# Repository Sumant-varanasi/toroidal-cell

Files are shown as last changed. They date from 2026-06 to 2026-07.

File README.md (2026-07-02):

# Toroidal Multipass Cell (TMPC) Platform

A Python toolkit for **designing, simulating, tolerancing, and visualising
Toroidal Multipass Cells** (TMPC) for laser absorption spectroscopy at 1.654 µm
(CH₄). The project pairs a custom 3-D ray tracer with an astigmatic
Gaussian-beam model, a full Monte-Carlo tolerance engine, multi-objective design
exploration, and interactive 3-D / photorealistic visualisation.

Multipass cells fold a long optical path into a compact volume by bouncing a
laser many times between mirrors — the more path, the more sensitive the gas
sensor. This repository explores toroidal-mirror geometries that support both
Herriott-style *ring* patterns and Tuzson/Graf-style *spiral* (up-down)
patterns, and provides the tooling to pick, tolerance, and validate a real
design.

The current, definitive model lives in
**[`_CURRENT/tmpc_platform_v5/`](_CURRENT/tmpc_platform_v5/)** — a self-contained
superset of the earlier iterations.

## Headline result — verified drone cell designs (July 2026)

**[`_CURRENT/drone_20m/`](_CURRENT/drone_20m/README.md)** holds a menu of
**fully verified drone-mountable designs using only catalog Thorlabs 1″ gold
mirrors** (N = 8–16, exact 3-D ray trace, Optiland-cross-validated, every
physical check enforced):

| envelope | OPL | throughput @ R=0.985 | build |
|---|---|---|---|
| Ø180 mm | **24.8 m** | 7.1 % | 16 × CM254-200-M01 |
| Ø180 mm | **20.4 m** | **11.5 %** | 16 × CM254-150-M01 (preset `drone_20m`) |
| Ø159 mm | **20.6 m** | 7.9 % | 13 × CM254-050-M01 (preset `drone_16cm`) |
| Ø143 mm | 13.6 m | 13.8 % | 12 × CM254-250-M01 |

(Published toroidal cells of this size class demonstrate ~10 m.) Each design
ships with an as-built spec — machined mirror placements, mode-matching lens
setting, launch tilts, detector pickoff, per-mirror spot maps — plus
Monte-Carlo tolerances and an ROC-compensation assembly rule.

<p align="center">
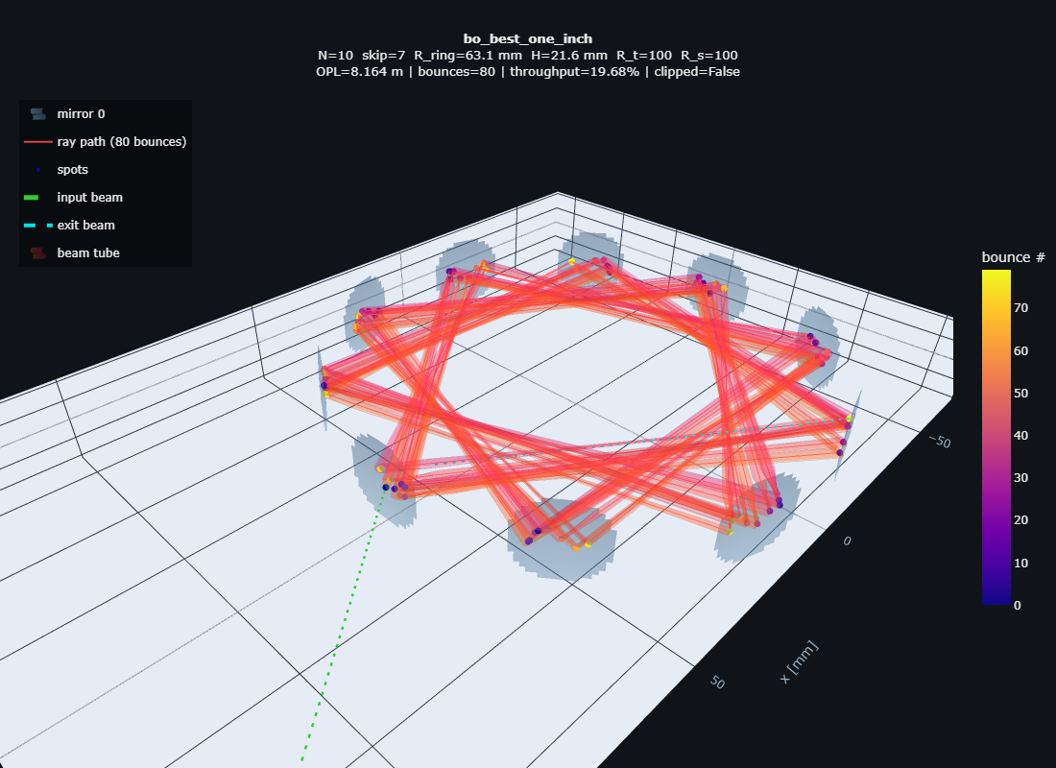
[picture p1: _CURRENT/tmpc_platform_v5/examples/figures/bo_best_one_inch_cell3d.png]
3D ray path + beam tube
  
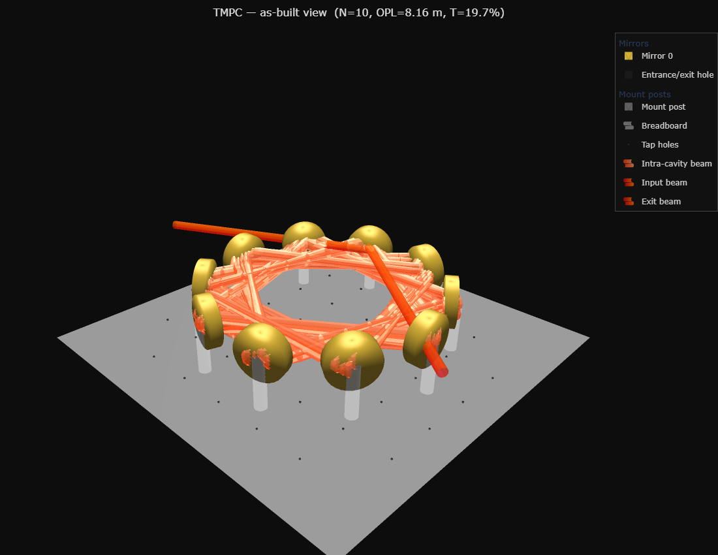
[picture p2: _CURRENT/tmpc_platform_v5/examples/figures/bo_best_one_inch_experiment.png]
As-built experiment render
  
</p>

*Left: the true ray-traced path with the beam rendered as a tube. Right: the
same cell as an "as-built" assembly — gold 1" mirrors, mounts, breadboard, and
the laser bouncing through it.*

---

## Repository layout

The definitive model is consolidated under **`_CURRENT/`** for easy access; the
older iterations remain at the repo root for reference.

| Path | Description |
| --- | --- |
| **`_CURRENT/`** | **Everything current** — the definitive model, gathered together |
| **`_CURRENT/tmpc_platform_v5/`** | **Latest platform.** Full physics, tolerancing, optimisation and visualisation. |
| `_CURRENT/tmpc_platform_v5/examples/` | Rendered figure gallery (3-D views, as-built renders, spot constellations, tolerance plots). |
| `tmpc_platform_v4/`, `tmpc_platform_v2/`, `tmpc_platform/` | Earlier iterations, kept for reference. |
| `run.py` | Standalone Optiland cross-validation of the ray tracer. |
| `test.py` | Quick checks / scratch script. |
| `.venv/`, `requirements.txt` | Shared Python runtime and pinned dependencies. |
| `file_toroidal_cell/`, `toroidal-cell/`, `files (1)/`, `files (2)/` | Historical archives and generated artefacts (CSVs, figures). |

See the **[figure gallery](_CURRENT/tmpc_platform_v5/examples/README.md)** for the
full set of rendered outputs.

<p align="center">
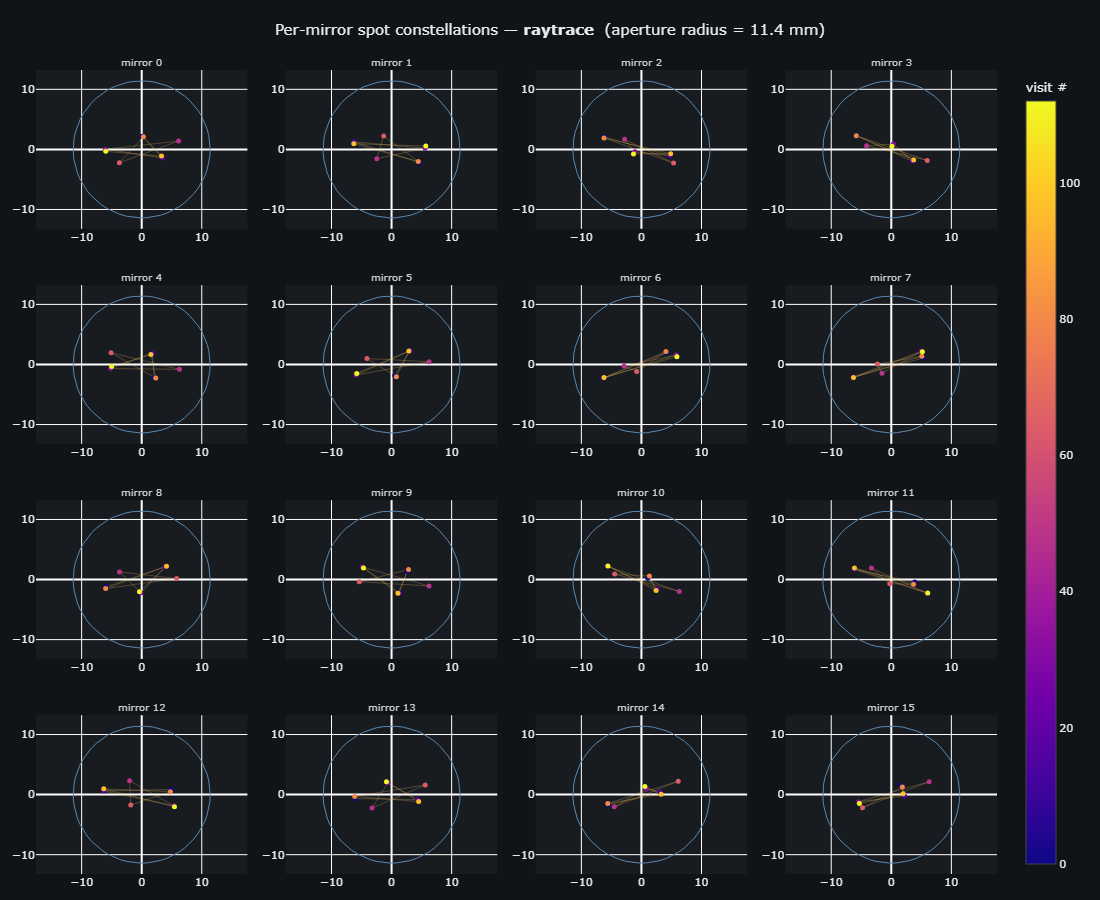
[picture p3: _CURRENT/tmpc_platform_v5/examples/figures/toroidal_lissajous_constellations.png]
Per-mirror spot constellations
  
</p>

*Per-mirror spot pattern for a toroidal (R_t ≠ R_s) design — the astigmatic
Lissajous footprints on each mirror face.*

---

## What v5 does

**Physics** (`physics.py`, `beam.py`) — exact 3-D ray tracing on toroidal mirror
surfaces (analytic normal, Newton-iterated intersection) with per-bounce
angle-of-incidence and hard-aperture clipping. Two topologies are supported: a
*ring* (Herriott-style rotating polygon) and a *spiral* (up-down) cell. Beam
propagation uses a realistic astigmatic M²-corrected Gaussian model in which the
tangential and sagittal radii evolve independently. A loss budget, isotropic and
per-plane stability, re-entrance score, volume utilisation, and spot-pattern
diagnostics are all computed.

**Tolerances** (`tolerance.py`) — per-mirror and global truncated-normal
perturbations, a Monte-Carlo yield study with continuous walk-off metrics,
one-at-a-time sensitivity analysis, and an RSS tolerance-budget allocator.
Presets range from loose to flight-grade, with thermal and vibration factories.

**Visualisation** (`viz3d.py`, `render.py`, `plots.py`) — interactive Plotly 3-D
cell views with the real ray path and beam tube, per-mirror spot constellations,
a photoreal "as-built" render, and publication-ready matplotlib figures.

**Design exploration & validation** — Sobol/LHS sampling with Thorlabs catalogue
snapping, parallel dataset generation, random + Bayesian optimisation, a
RandomForest surrogate, a dependency-free Pareto front, and validation via
analytic cross-checks, ABCD-vs-raytrace residuals, and optional Optiland
cross-validation.

---

## Installation

```bash
git clone https://github.com/Sumant-varanasi/toroidal-cell.git
cd toroidal-cell
python -m venv .venv
# Windows: .venv\Scripts\activate  |  Linux/macOS: source .venv/bin/activate
pip install -r requirements.txt
```

Core dependencies are NumPy, SciPy, pandas and matplotlib. Optional features use
`plotly`, `optiland`, `scikit-optimize` and `scikit-learn`; these are
soft-imported and skipped with a clear message if absent.

> The model is invoked as a package (`python -m tmpc_platform_v5 …`), so run the
> commands **from inside `_CURRENT/`** where the package lives. The examples
> below use the shared virtualenv one level up at `../.venv`.

---

## Quick start (CLI)

```bash
cd _CURRENT
PY=../.venv/Scripts/python.exe   # Linux/macOS: ../.venv/bin/python

# list named design points and simulate one
$PY -m tmpc_platform_v5 presets
$PY -m tmpc_platform_v5 simulate --preset longest_opl

# one design from raw parameters, full physics report
$PY -m tmpc_platform_v5 simulate --N 12 --R_ring 60 --R_t 120 --R_s 180 --chord_skip 5

# Monte-Carlo tolerance study (sensitivity + RSS budget + plots)
$PY -m tmpc_platform_v5 tolerance --preset bo_best_one_inch --tol-preset research --n-trials 300

# interactive 3-D + spot constellations, and an "as-built" render
$PY -m tmpc_platform_v5 visualize --preset toroidal_lissajous --out-dir results/viz
$PY -m tmpc_platform_v5 render --preset bo_best_one_inch --out results/render/exp.html

# physics validation (analytic + ABCD + Optiland if installed), and a Pareto front
$PY -m tmpc_platform_v5 validate --N 8 --chord_skip 1
$PY -m tmpc_platform_v5 pareto --n 512
```

## Quick start (Python API)

```python
from tmpc_platform_v5 import TMPCConfig, simulate_tmpc, ToleranceSpec, full_report

cfg = TMPCConfig(N=12, R_ring=60, H=40, R_t=120, R_s=180,
                 chord_skip=5, w0=0.5, M2=1.1, input_offset_z=-2.0)
cfg.n_passes = 8 * cfg.N
res = simulate_tmpc(cfg)
print(res.bounces, res.opl, res.throughput, res.stability_tan, res.stability_sag)

# full tolerance report (Monte-Carlo + sensitivity + budget)
rep = full_report(cfg, ToleranceSpec.research_grade(), n_trials=300, metric="exit_drift_mrad")
print(rep["summary"], rep["sensitivity"], rep["budget"])
```

## Conventions

All lengths are in millimetres, wavelength in mm (`1.654e-3` = 1654 nm), and
angles in radians unless a name ends in `_deg`/`_mrad`.

## Validating the ray tracer

`run.py` rebuilds the same cell geometry in the open-source
[Optiland](https://github.com/HarrisonKramer/optiland) package and compares
per-bounce spot positions, chord length, and angle of incidence against the
custom NumPy tracer.

---

> IP note: per the IITD-Abu Dhabi / Aston joint brief, all IP belongs to Aston.
> Internal use only.

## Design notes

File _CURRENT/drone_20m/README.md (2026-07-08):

# Drone TMPC design suite — verified 1″-mirror cells, Ø140–180 mm, 13.6–24.8 m OPL

Design brief (2026-07-02): a drone-mountable toroidal multipass cell for CH₄
TDLAS at 1654 nm — target ~20 m OPL, assembly diameter safely under 190 mm
(smaller better), **N = 8–16** Thorlabs 1″ protected-gold concave mirrors
(CM254-xxx-M01), entrance-hole radius 1.3 mm, 1.3 mm collimated input beam,
reflectivity assumed 0.984–0.985 (throughput reported parametrically in R).

Every design below is verified by the exact 3-D ray tracer
(`tmpc_platform_v5`) against the full physical-check matrix: exit through the
entrance hole, no early hole leakage, 1/e² beam edge inside every clear
aperture, no spot overlap anywhere (fringe safety), per-plane astigmatic
stability, mirror packing, and the envelope cap. Optiland cross-validation
reproduces the traced path to 0.000 µm RMS.

<p align="center">
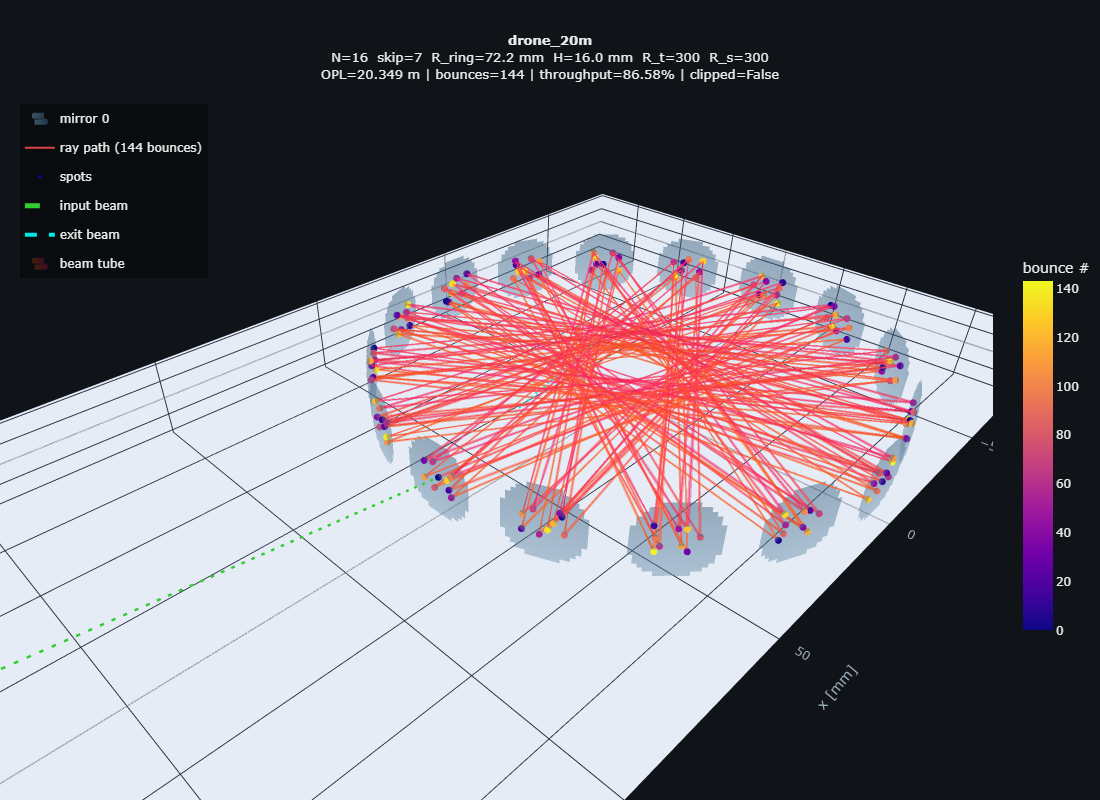
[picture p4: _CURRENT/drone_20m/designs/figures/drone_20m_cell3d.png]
drone_20m: 144-bounce light path in the 16-mirror ring
  
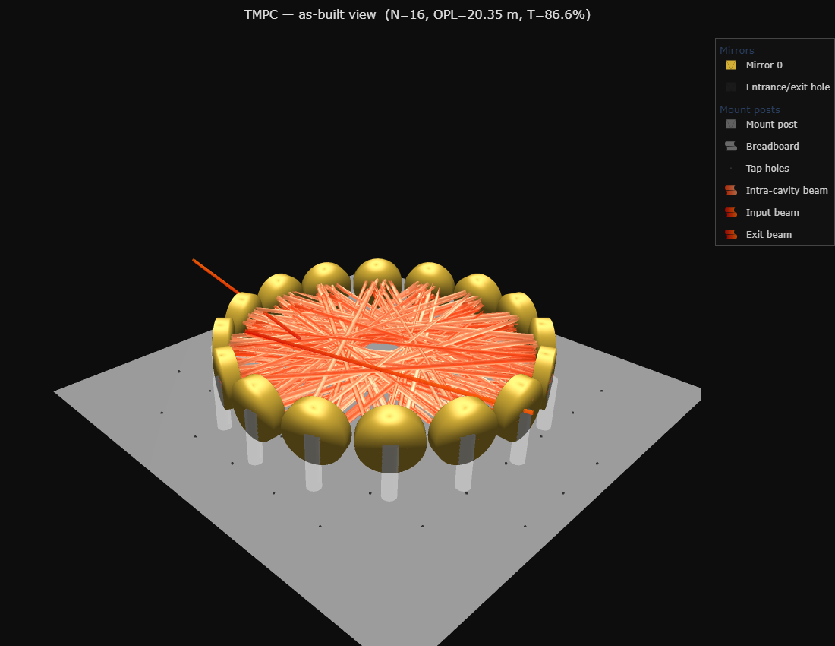
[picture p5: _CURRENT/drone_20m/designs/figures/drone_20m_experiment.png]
drone_20m as-built render
  
</p>

*Left: the traced light path of `drone_20m` — 144 chords between 16 catalog
mirrors, input (green) and exit beams through the hole in mirror 0.
Right: the same cell rendered as built. Interactive versions:
[cell3d.html](designs/figures/drone_20m_cell3d.html),
[experiment.html](designs/figures/drone_20m_experiment.html).*

<p align="center">
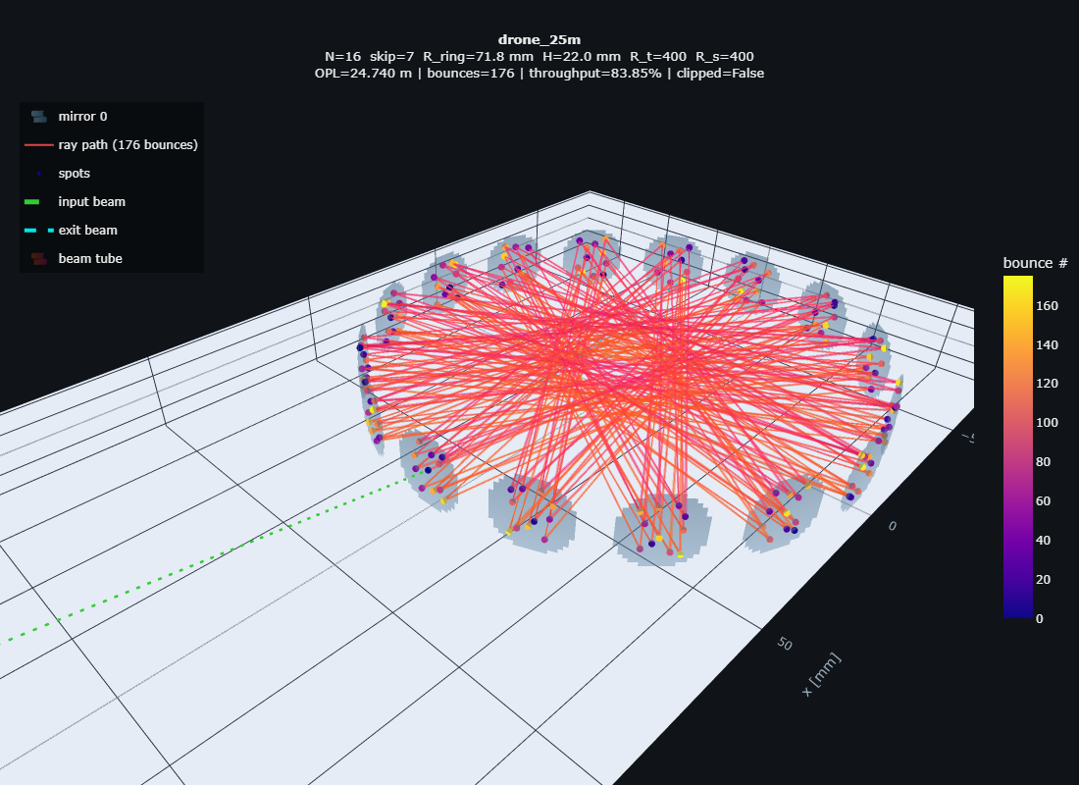
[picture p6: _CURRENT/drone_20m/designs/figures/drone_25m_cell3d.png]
drone_25m: 176-bounce light path (24.8 m)
  
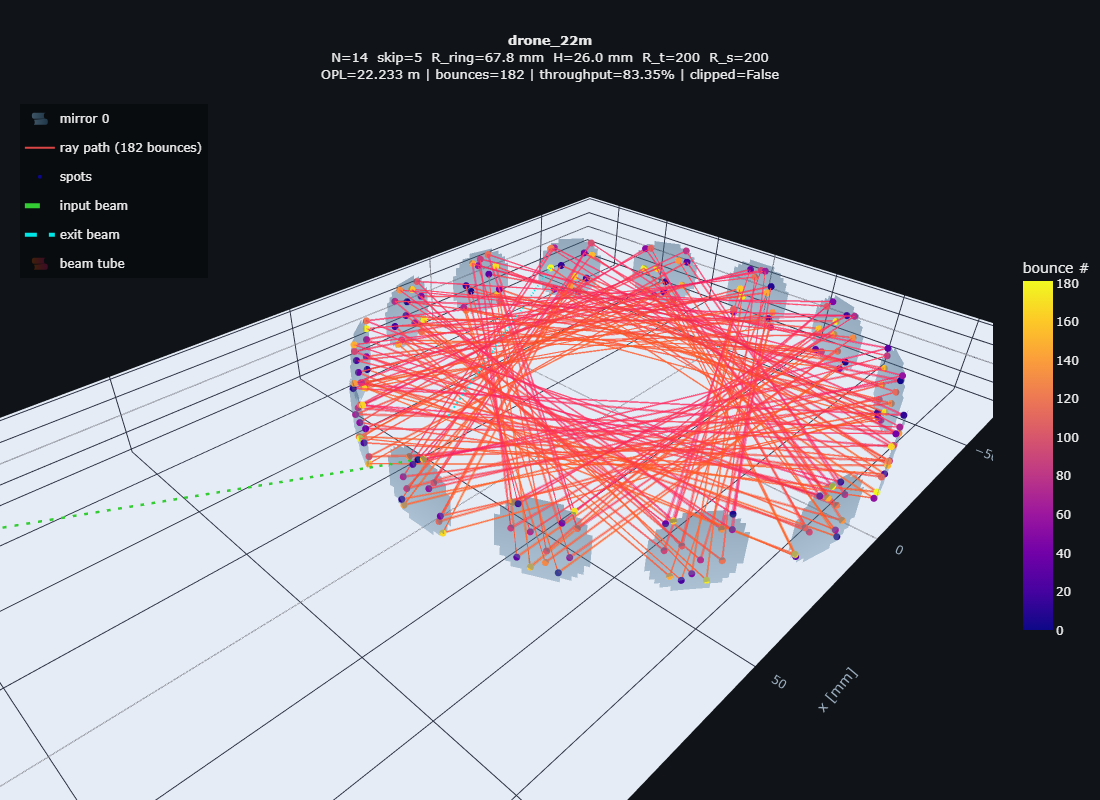
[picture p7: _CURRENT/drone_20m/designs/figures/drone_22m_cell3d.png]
drone_22m: 182-bounce light path (22.3 m)
  
</p>

*The longer-path corners: `drone_25m` (left — 176 chords, 24.77 m, 11 spots
per mirror in the same 180 mm envelope) and the new `drone_22m` (right —
182 chords, 22.25 m in 172 mm). At R = 0.999 these extra passes cost only
~3 % of signal.*

<p align="center">
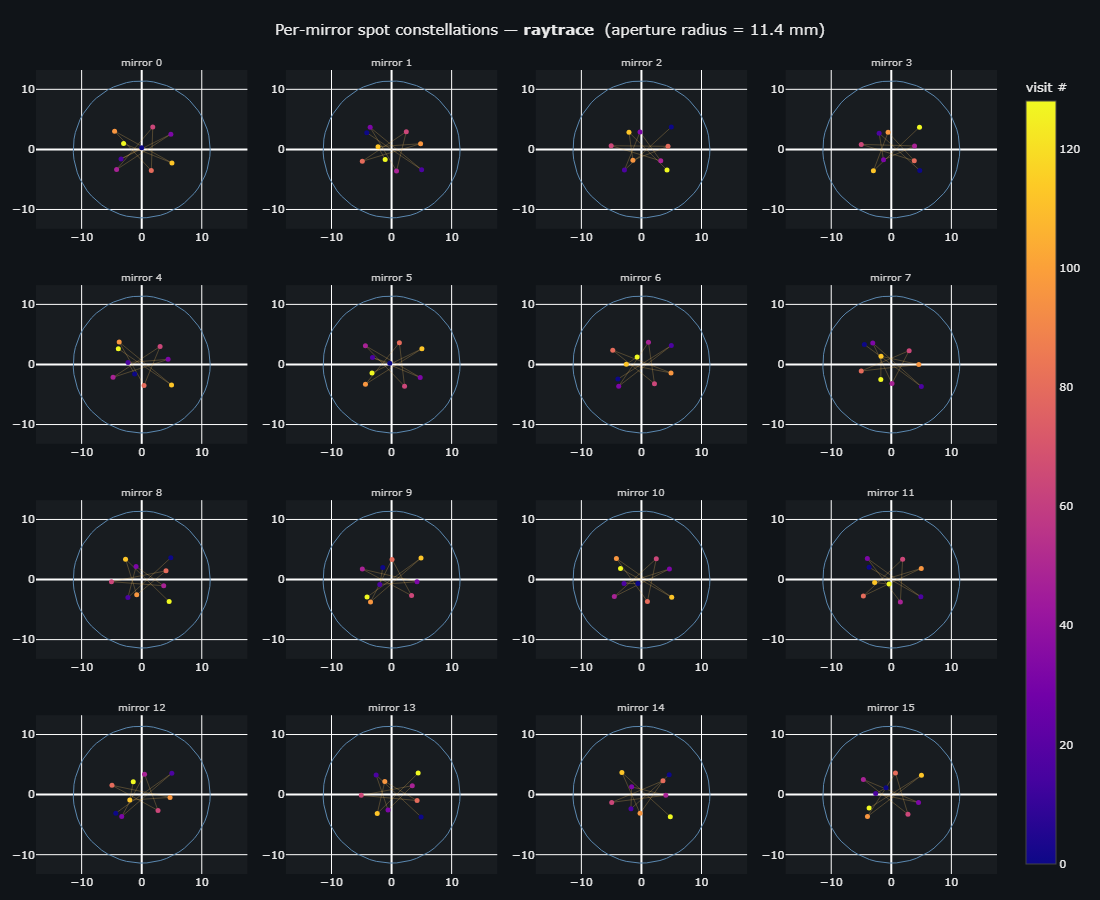
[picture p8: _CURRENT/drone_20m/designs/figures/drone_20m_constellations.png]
per-mirror spot constellations
  
</p>

*The 9-spot constellation each mirror carries — same Lissajous, different
phase origin per mirror; worst pair distance is a verified check.*

## The tolerance-tiered menu

Transmission at **R = 0.999** (the project's mirrors); the hole is lossless
so **T(R) = R^(chords−1) exactly** for any other coating. Every design
passes the full check matrix in the exact trace **and** a 100-trial
Monte-Carlo at the stated build grade with physical criteria: full path
completes in every trial, spots never merge, intermediate spots keep
clearing the hole, and the exit still leaves the 1.3 mm hole with **no
realignment** ([robust_menu.csv](designs/robust_menu.csv) /
[flight](designs/robust_menu_flight.csv)).

**Tier 1 — standard lab build** (kinematic mounts, 0.5 mrad tilt class):

| design | mirrors | chords | **OPL** | T @0.999 | envelope | preset |
|---|---|---|---|---|---|---|
| standard-build corner | 16 × CM254-150 (ROC 300) | 144 | 20.38 m | 86.7 % | Ø180 | `drone_20m` |

**Tier 2 — precision (flight-grade) build** (glued/welded, 0.1 mrad tilt
class — the drone-vibration spec anyway):

| design | mirrors | chords | **OPL** | T @0.999 | envelope | preset / spec |
|---|---|---|---|---|---|---|
| **max OPL** | 12 × CM254-750 (ROC 1500) | 204 | **28.99 m** | 76.6 % | Ø183 | `drone_29m` · [spec](designs/spec_D190_29m.md) |
| long | 16 × CM254-200 (ROC 400) | 176 | **24.77 m** | 83.9 % | Ø180 | `drone_25m` (walk-budget variant) |
| **compact star** | 12 × CM254-500 (ROC 1000) | 204 | **20.66 m** | 81.6 % | **Ø141** | `drone_14cm` · [spec](designs/spec_D150_14cm.md) |
| balanced | 13 × CM254-150 (ROC 300) | 143 | 16.60 m | 86.8 % | Ø160 | [spec](designs/spec_D170_maxT.md) |
| small | 10 × CM254-150 (ROC 300) | 190 | 14.85 m | 82.8 % | Ø133 | — |
| small max-T | 12 × CM254-250 (ROC 500) | 132 | 13.64 m | 87.7 % | Ø143 | [spec](designs/spec_D150_maxOPL.md) |

Robustness-by-design findings (search v8): demanding 0.55 mm clearances
during the search hardened the surviving designs (drone_20m's worst-case
p05 separation grew 0.94 → 1.23 mm; the 24.8 m design was **promoted**
into this tier), while the 1/sin θ error-amplification gate was
empirically falsified — the near-planar long-ROC family it would exclude
is exactly what wins here. Pattern walk grows ~√chords with build error,
so the standard-tolerance ceiling sits near 145 chords; a drone needs the
glued/welded construction for vibration regardless, making this tier the
operative drone menu.

**Tier 3 — active alignment required** (feasible nominal designs whose
dense patterns exceed passive build tolerances): **26.7 m/Ø157** (12 ×
CM254-075, 228 chords — new, v9 deep search), 24.8 m/Ø180 (`drone_25m`),
22.0 m/Ø155, 22.3 m/Ø172 (`drone_22m`), 20.6 m/Ø159 (`drone_16cm`), up
to **38.6 m/Ø169** (14 × CM254-100, 322 chords, 72.5 %) — the geometric
ceiling of the architecture; buildable only with in-situ trim (ring
temperature + launch piezo) or sub-0.1 mrad machining. A second, deeper
search pass (walk-budget 0.55, top-200/refine-80) found **no additions
to the flight-robust tier** — the Tier-2 menu is the converged robust
frontier of this architecture, not a sampling artifact.

The tier structure is the quantitative answer to "smaller, longer, and
tolerant": at R = 0.999 the photon budget allows ~700 reflections, so the
limit is spot-pattern geometry under build error — 20.4 m at standard
tolerances, 29 m at flight-grade, 39 m only with active alignment.

**Verified boundary**: Ø141 mm is the smallest feasible envelope found
(N ≥ 8 packing floor is Ø105). Best near-miss outside it: 18.0 m in Ø140 mm
failing only by an intermediate spot grazing the hole by 0.56 mm — placing
the hole at a different constellation slot (tangential launch offset) is the
open lever.

## Professor-feedback round (2026-07-08) — comparisons, tri-gas, windows, manufacturing

Six new studies answer Dr. Benoy's review of the draft
([full docs in designs/](designs/)):

- **[IRsweep IRcell + literature comparison](designs/irsweep_comparison.md)**
  — the closest commercial cell (IRcell-S15) folds 15.12 m into Ø194 mm /
  128 mL; our 20.38 m in Ø180 is +35 % path in a smaller disc at 86.7 %
  verified throughput, with catalog mirrors instead of a diamond-turned
  monolith. **Beams do not overlap**: worst same-mirror spot pair sits
  2.8–4.6 beam radii apart → field coupling −34…−92 dB (the toroidal
  IRcell ancestor superposes beams by construction and needs a Teflon
  absorption mask). Volume is the honest downside: 200–330 mL minimum
  chamber vs their 31–128 mL; per litre we match the published toroidal
  family (70–127 m/L) with 2–5× their absolute path.
- **[Tri-gas menu](designs/multigas.md)** — CH₄ 1653.7 nm / NH₃ 1512.2 nm /
  H₂ 2121.8 nm. Geometry is wavelength-independent (spots scale √λ):
  NH₃ re-verifies the **entire 7-design flight menu as-built**; H₂
  (+13.3 % spots) keeps six designs including both 20 m cells, and a
  dedicated 2121.8 nm search recovered a **23.8 m / Ø174 H₂-robust**
  design. Detection limits at 20.4 m, 10⁻⁴ NEA: **129 ppb CH₄, 92 ppb
  NH₃, 0.17–0.31 %v H₂** (the quadrupole line is 10⁵ weaker — percent-LEL
  leak alarm in direct absorption, tens of ppm with WMS at 10⁻⁶).
  ⚠ line-label fix for the paper: 1653.73 nm is 2ν₃ **R(3)**, not R(4).
- **[Entry/exit: hole vs side](designs/entry_exit_comparison.md)** — the
  hole is a *transverse-selective* aperture: a side slot escapes at the
  first azimuthal return (N chords), capping the Ø180 ring at 2.3 m; the
  hole is worth exactly k = 9–19× in path.
- **[Window selection](designs/window_selection.md)** — **WW10530-C**
  (Ø1/2″ UVFS wedged, AR 1050–1700 nm) for NH₃+CH₄ and **WW30530-D**
  (Ø1/2″ **sapphire** wedged, AR 1.65–3.0 µm) for CH₄+H₂; 30 arcmin wedge
  + 3–5° mount tilt (ghost walk-off ~30× beam divergence; measured 23×
  fringe suppression precedent). CaF₂ rejected on numbers: sapphire is
  ~10× harder, ~12–19× stronger in rupture, ~4–6× tougher.
- **[Manufacturing & construction tolerance](designs/manufacturing.md)** —
  process-capability-mapped Monte-Carlo: dense 204-chord designs survive
  only precision-CNC Al; the sparse 144-chord `drone_20m` completes 100 %
  even on standard CNC or a printed body with machined seats (fails only
  the *no-realignment* exit spec by 20 µm → fine after the standard one
  trim). A fully-printed $200 cell fails three independent ways
  (as-printed accuracy, CTE/moisture drift, lid modes 327–535 Hz inside
  the 60–700 Hz rotor band). CNC Al at one-off quantities costs the same
  as a good print. Housing mass: 1.7 kg solid → ~1.1–1.3 kg pocketed
  (Ø180, Al), lid first mode 1.24 kHz.
- **[Parametric CAD](designs/cad/)** — STEP (Fusion 360-ready) + STL for
  Ø141/Ø180/Ø183 housings, generated from the verified design rows
  (`housing_cad.py`), with mirror pockets, mirror-0 beam cone, window
  boss, gas ports; FEA/DFM handoff for the team.

<p align="center">
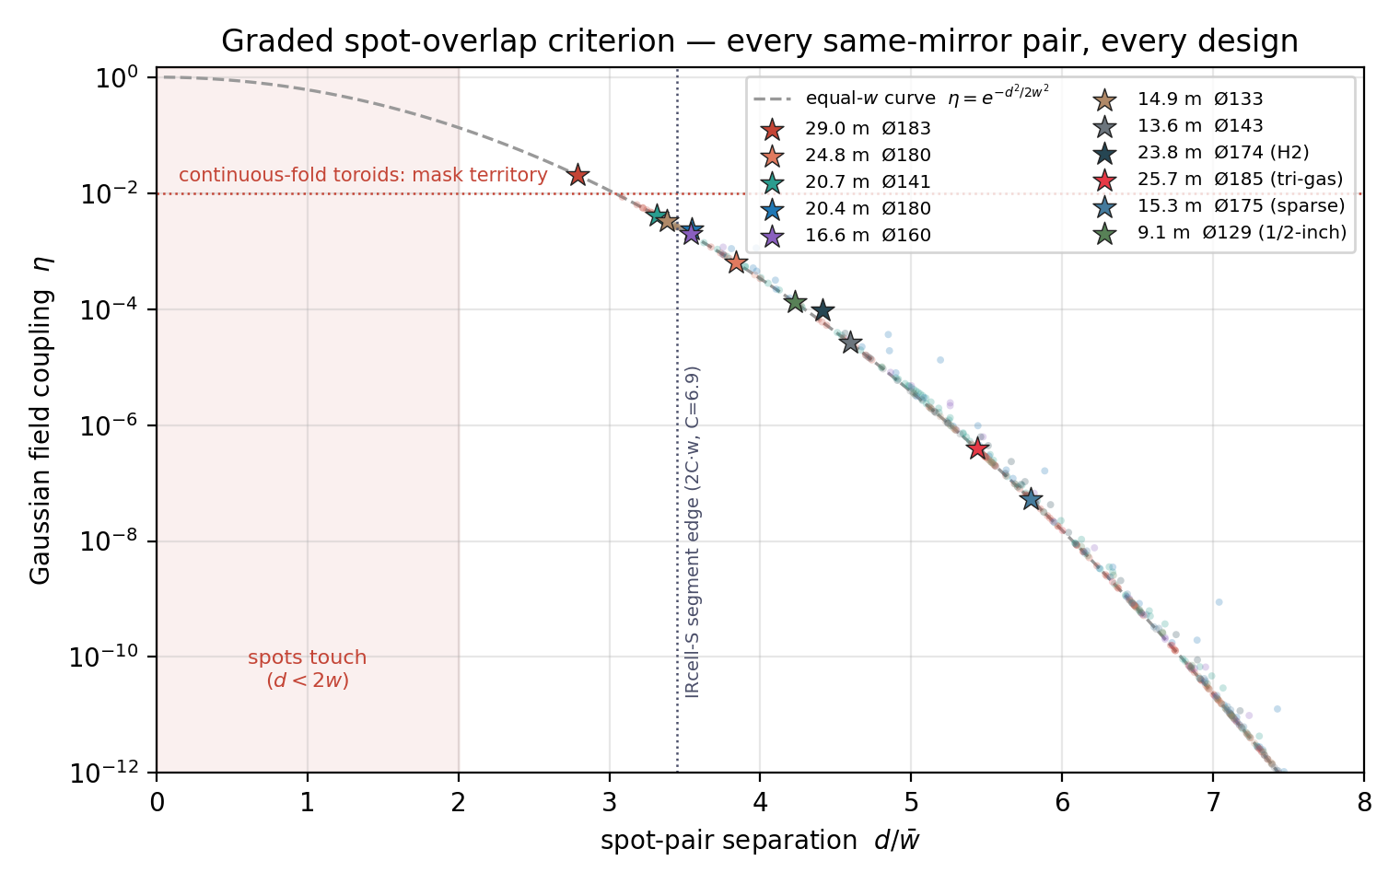
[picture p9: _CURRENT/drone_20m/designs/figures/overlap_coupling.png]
graded spot-overlap criterion
  
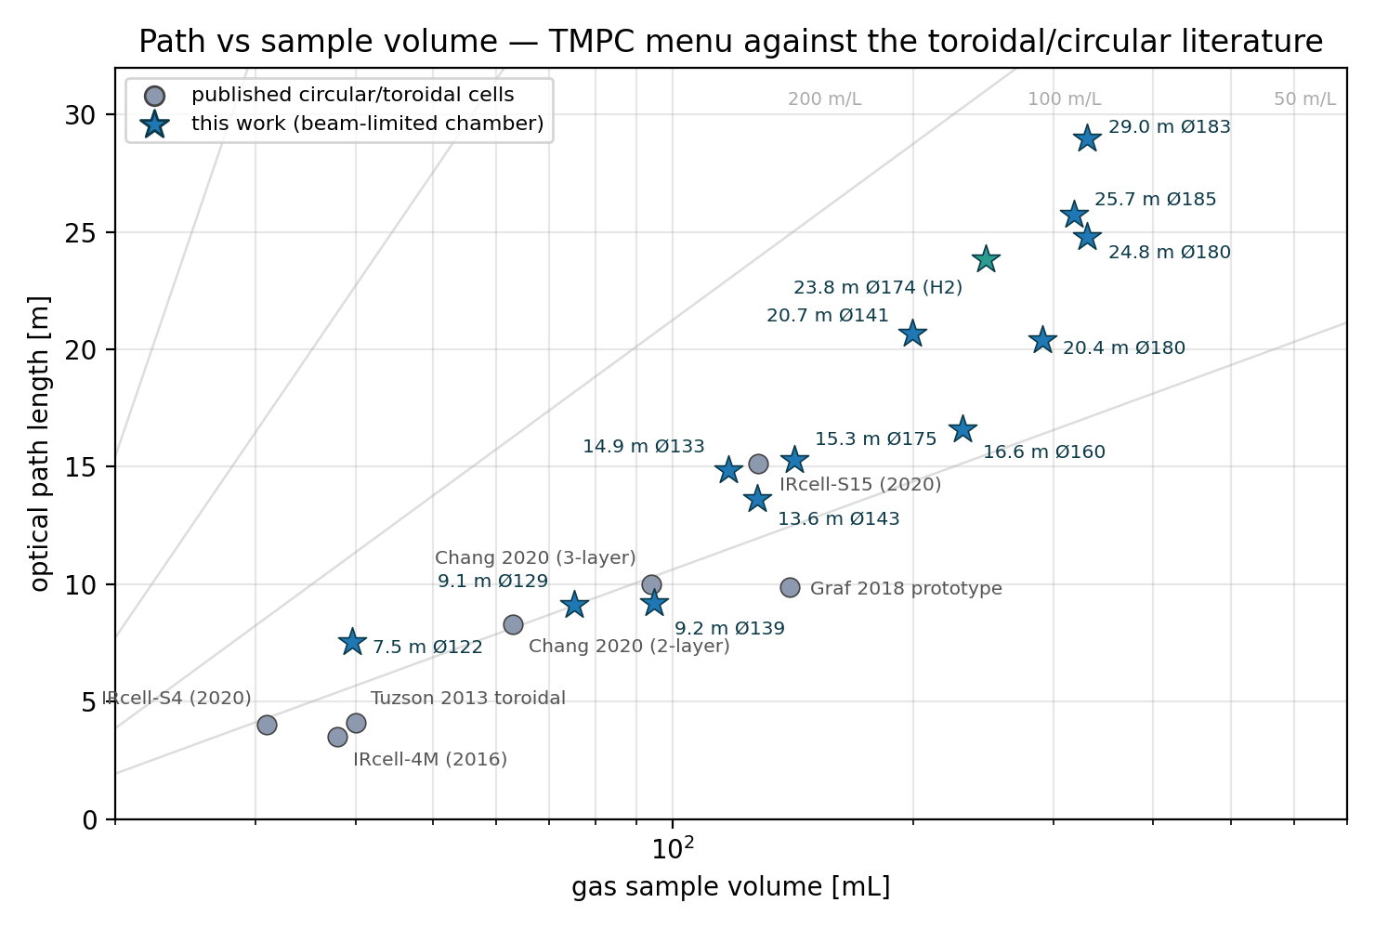
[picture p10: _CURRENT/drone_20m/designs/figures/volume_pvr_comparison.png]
path vs volume literature comparison
  
</p>
<p align="center">
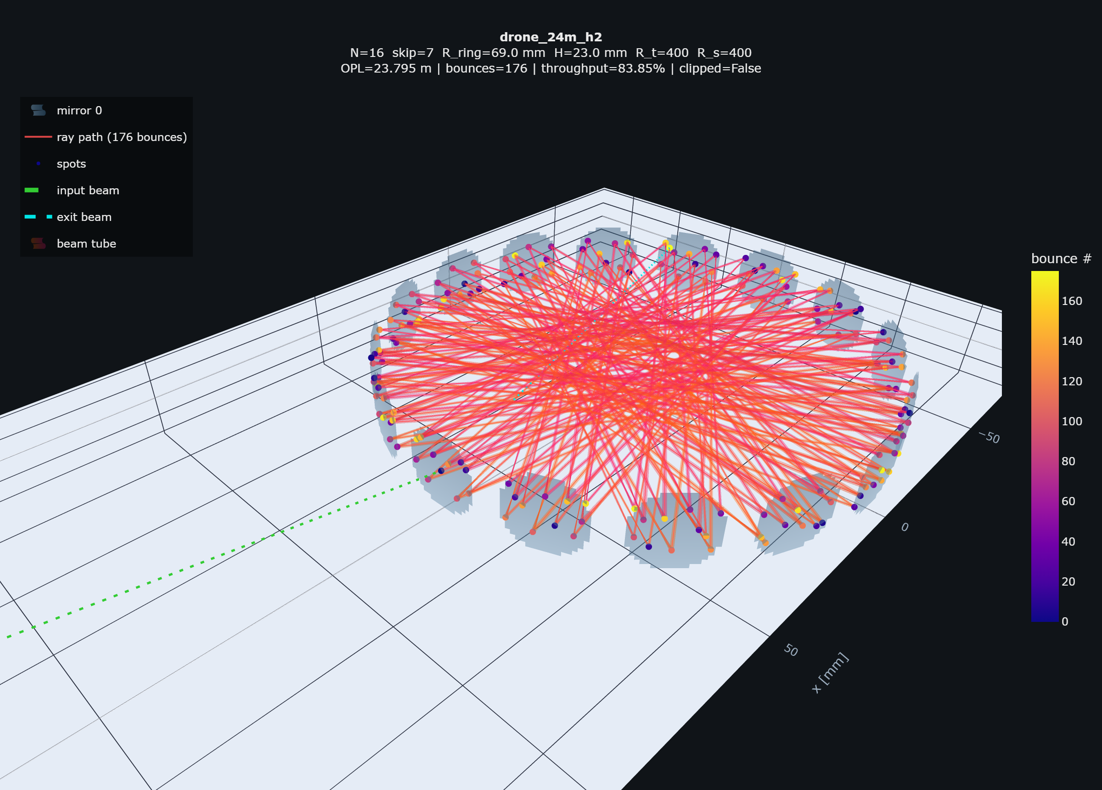
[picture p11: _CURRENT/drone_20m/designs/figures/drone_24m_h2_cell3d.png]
drone_24m_h2 traced path (H2, 2121.8 nm)
  
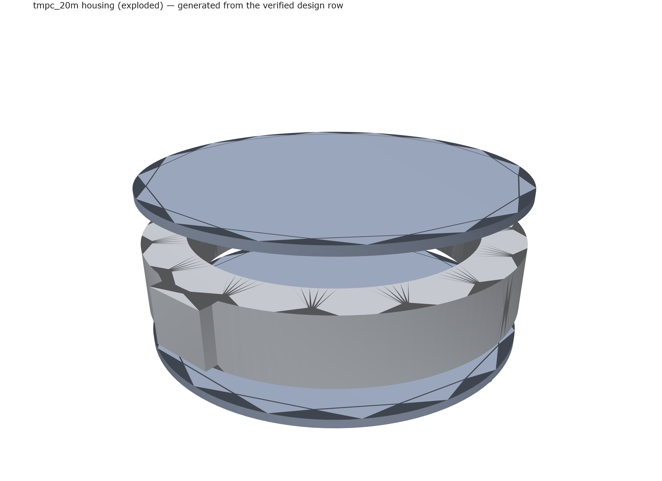
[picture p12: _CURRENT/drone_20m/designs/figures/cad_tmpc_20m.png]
tmpc_20m housing CAD render
  
</p>
<p align="center">
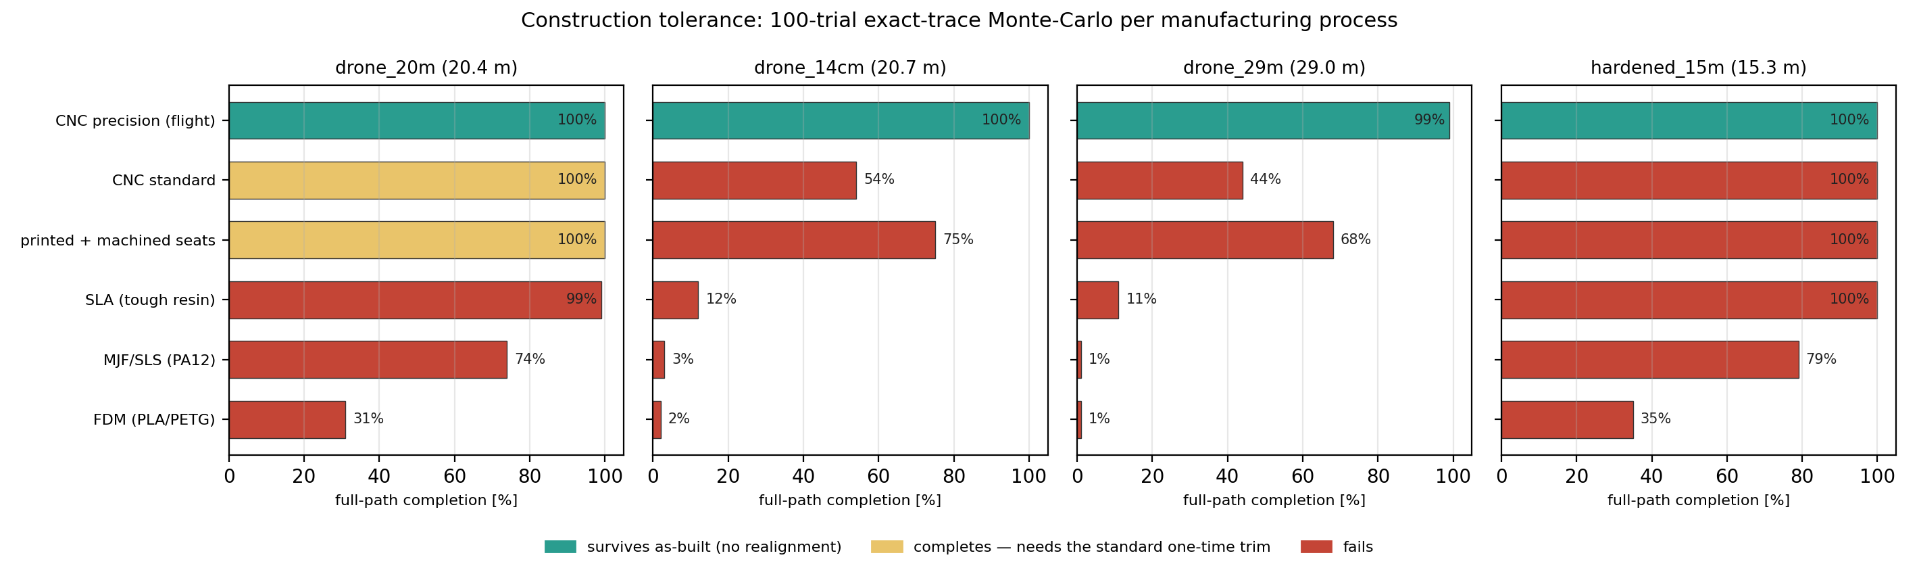
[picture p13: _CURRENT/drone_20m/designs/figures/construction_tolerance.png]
construction tolerance MC
  
</p>

*Feedback-round figure set (all in [designs/figures/](designs/figures/),
`_paper` = white print variants): the graded overlap criterion with the
IRcell-S reference, the path-vs-volume literature map, the new
Optiland-validated 23.8 m H₂ cell, the generated housing CAD, and the
manufacturing-process Monte-Carlo.*

## Variation-hunt round — new champions and complete-coverage audits

Further searches and audits on top of the feedback round
(one-page map for the reply: [PROF_RESPONSE_SUMMARY.md](designs/PROF_RESPONSE_SUMMARY.md)):

- **Tri-gas ceiling raised to 25.72 m / Ø185** (walk-hardened search;
  robust as-built at CH₄+NH₃+H₂, doubly confirmed by an H₂-native
  search converging on the same design; 400-trial MC flawless;
  [spec](designs/spec_D190_26m.md), ROC trim 0.75 mm/%, ±18 K Al).
- **15.30 m / Ø175 at 89.5 % with 7 spots/mirror** — the sparse
  budget-build corner: 100 % path completion on every process down to
  SLA; tri-gas robust ([spec](designs/spec_D180_15m_sparse.md)).
- **Low-volume half-inch family** ([low_volume_menu.md](designs/low_volume_menu.md)):
  flight-robust 7.54 m/Ø122/**40 mL** (PVR 190 m/L); with a 0.8 mm
  mini-collimator (decision pending): **9.11 m/Ø129/75 mL at 90.8 %**
  ([spec](designs/spec_D130_9m_halfinch.md) + `cad/tmpc_9m_mini`);
  showcase 19.3 m/Ø93/**37 mL** (PVR 518 m/L, active tier). Gas
  exchange 1–9 s pumped / ~25 ms open-flow.
- **Feature frontier** ([feature_frontier.md](designs/feature_frontier.md)):
  champions per criterion across all 14 MC-robust designs.
- **Operational physics audit** ([operational_audit.md](designs/operational_audit.md)):
  polarization Jones analysis (launch sagittal — 96.3–99.9 % eigenaxis
  purity; 45° launch exits up to 39° elliptical; skip-3 family
  diattenuates ×6.4), vibration-to-signal budget (ring tilt 0.01–0.1
  µrad/g, margin >10³ — coupling lives in the launch/detector chain),
  H₂ etalon-FSR audit (chord parasites sit ON the H₂ linewidth → spot
  separation is the H₂ enabler), plus bounded gravity/aero-optic/
  figure-error/dust/condensation/étendue effects.
- **Active-tier actuation spec** ([active_tier_requirements.md](designs/active_tier_requirements.md)):
  Tier-3 = two-loop control on parts every build already carries (ring
  heater 1.2–1.7 µm/K + launch piezo + quad behind the hole; ~$400–700
  delta buys 25.7 → 38.6 m).
- **Two-inch family** ([study](designs/two_inch_family.md)): under the
  Ø190 cap CM508 mirrors pack at N = 7–8 only; verified flight-robust:
  **19.04 m/Ø182 at 86.0 % with just 8 mirrors** and 11.6 m/Ø187 at
  90.1 % with 7. The 19 m design is the first whose full path completes
  in **100 % of Monte-Carlo trials at every manufacturing grade
  including desktop FDM** (one-trim caveat) — the published printed-cell
  record is 4.2 m. High-k 2″ patterns (needed to beat 29 m) sit beyond
  the paraxial prescreen inside this envelope — larger apertures win
  only in relaxed envelopes.
- **Mixed-SKU rings** ([full study](designs/mixed_sku_study.md)): two
  alternating catalog ROCs give the architecture a second closure knob
  — the alternating unit cell closes (N, s, k) patterns no single ROC
  can. Verified: **51.66 m in Ø180** (12 × alternating
  CM254-250/CM254-375, 372 chords, 69 % at R = 0.999, exit miss 2.3 µm,
  hole clearance +2.5 mm) — the architecture's nominal ceiling moves
  38.6 → 51.7 m (+34 %), mix-only by counterfactual, active-alignment
  tier (worst-pair margin +0.03 mm). The 55–69 m closures found stay
  spot-crowded on 1″ apertures; 2″ mirrors or a margin-aware mixed
  search are the quantified route to making them robust.

## Engineering studies ([full report](designs/investigations.md))

- **ROC-error compensation** (Thorlabs f is ±1 %): perfectly linear ring
  trim — 0.72 mm per 1 % for the Ø180 designs, 0.62 mm for `drone_16cm` —
  restores full feasibility across the whole band. Assembly rule: measure
  the delivered ROC, machine the ring to the interpolated radius, walk in
  the last µm with the temperature/shim trim.
- **Thermal window** (aluminium ring, launch frozen, all checks passing):
  `drone_20m` **±26 K**, `drone_25m` ±20 K, `drone_16cm` ±8 K; an invar
  ring holds ≥ ±30 K everywhere. Plain 6061 is fine for the headline
  design under drone conditions.
- **Beam quality**: all three designs pass every check up to **M² = 1.3**
  — comfortably beyond real DFB + fiber-collimator sources.

Where this sits in the literature: the published toroidal record in the
~100–145 mm class is ~10 m demonstrated (Graf 2018 segmented, Chang 2020
multi-layer; Chang's 30 m was theoretical only). **20.6 m verified in a
159 mm envelope / 20.4 m at 11.5 % throughput in 180 mm** sits well beyond
that, using only catalog mirrors and the project's chord-skip degree of
freedom.

## The physics that made it work

1. **Chord-skip ring geometry** (the project's contribution): s ≈ N/2 gives
   near-diameter chords (AOI 7–13°), so 140+ mm of path per bounce fits in a
   sub-190 mm ring.
2. **Re-entrance closure**: the transverse (Herriott) phases must return to
   the hole. Both planes' accumulated phases n·θ must hit a multiple of 2π
   (or π for zero-crossing launches — 4 closure-mode combinations per
   geometry). The machined **ring radius is the closure-tuning knob**
   (~1.2 rad of accumulated phase per mm), polished against the
   catalog-locked ROC; residual per-plane mismatch is absorbed by the launch
   amplitudes. Final exit miss: 10⁻⁶–10⁻⁴ mm.
3. **Constellation number theory**: with k spots per mirror (k odd, and the
   full n-point Lissajous evaluated on *every* mirror — each mirror sees the
   same pattern at a different phase origin), the worst spot pair and the
   hole clearance are exact analytic quantities. Degenerate (M, k)
   combinations are filtered before any ray is traced.
4. **Mode-matched injection**: the 1.3 mm collimated input is focused by a
   small lens to the cell eigenmode (waist ~0.20–0.33 mm placed ~0.5–1.4
   half-chords past the hole). The beam then rides the cell at 0.21–0.42 mm
   for all bounces: spots stay separated, apertures are trivial, and the
   1.3 mm hole passes ~100 % (vs 86.5 % per pass for a waist-at-hole
   launch). Exit beam re-images to the injection q — it leaves through the
   same hole at 2×AOI from the input axis, onto the detector.

## Tolerances (drone_20m headline, 400-trial Monte-Carlo, research grade)

σ: mirror tilt 0.5 mrad, decenter 50 µm lateral / 100 µm axial, ROC 1 mm,
R_ring 0.1 mm, launch 50 µm / 0.5 mrad. Results: **zero clipping in 400
trials**, bounces always 144, OPL 20.35 ± 0.03 m, throughput 11.5 ± 1.7 %,
exit pointing drift 4.2 ± 2.6 mrad (0.2 mm on a detector 50 mm behind M0),
spot-pattern walk p95 = 0.89 mm vs 1.46 mm hole clearance. Sensitivity
order: mirror tilt > ring radius > lateral decenter ≫ ROC error — i.e. the
one-piece machined ring with press-fit pockets is the right build, and the
Thorlabs ±1 % focal-length tolerance is compensated at assembly by the
R_ring shim/temperature trim (see the spec sheets).

Figures: [`designs/figures/`](designs/figures/) — interactive 3-D cell +
beam tube, per-mirror constellations, as-built render, MC histograms,
sensitivity bars, RSS budget.

## Reproduce

```bash
cd _CURRENT
PY=../.venv/Scripts/python.exe

# the full 9-class search (~7 min on 16 cores)
$PY drone_20m/search_drone20m.py --workers 16 --top-per-class 120 --refine-top 50

# as-built spec sheets for every feasible class corner
$PY drone_20m/spec_asbuilt.py

# platform-level verification of a headline design
$PY -m tmpc_platform_v5 simulate  --preset drone_20m
$PY -m tmpc_platform_v5 validate  --preset drone_20m
$PY -m tmpc_platform_v5 tolerance --preset drone_20m --tol-preset research \
    --n-trials 400 --metric exit_drift_mrad --out-dir results/drone_20m_tol
$PY -m tmpc_platform_v5 visualize --preset drone_20m --out-dir results/drone_20m_viz
$PY -m tmpc_platform_v5 render    --preset drone_20m --out results/drone_20m_viz/experiment.html
```

Presets: `drone_20m`, `drone_25m`, `drone_16cm`. Design JSONs + per-design
as-built specs (machined placements, lens focus, launch tilts, detector
pickoff, spot maps, check matrices) live in [`designs/`](designs/).

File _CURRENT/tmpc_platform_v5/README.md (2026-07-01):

# TMPC Platform v5 — definitive toroidal-multipass-cell model

A single, self-contained platform for designing, simulating, **tolerancing**, and
**visualising** Toroidal Multipass Cells (TMPC) for laser absorption spectroscopy
at 1.654 µm (CH₄). It is the superset of every earlier version in this repo, plus
the things they were missing: realistic astigmatic beam propagation, a full
tolerance/Monte-Carlo engine, two cell topologies, and true 3-D + "as-built"
visualisation.

> Use the project virtual-env interpreter: `./.venv/Scripts/python.exe`
> (it has numpy, scipy, pandas, matplotlib, plotly, scikit-learn,
> scikit-optimize, optiland). Run all commands from the repo root so
> `import tmpc_platform_v5` resolves.

**See the [figure gallery](examples/README.md)** for rendered 3-D cell views,
as-built renders, spot constellations, and tolerance-analysis plots.

---

## What it does (capability map)

**Physics (`physics.py`, `beam.py`)**
- Exact 3-D ray tracing on toroidal mirror surfaces (implicit torus, analytic
  normal, Newton-iterated intersection) with per-bounce angle-of-incidence and
  hard-aperture clipping.
- Two topologies:
  - `ring` — Herriott-style rotating polygon, beam advances `chord_skip` mirrors
    per bounce (real ray-traced helix when launched off-plane).
  - `spiral` — Tuzson/Graf up-down cell: enter a hole at z = −H/2, spiral up,
    hit a top retroreflector, spiral back down, exit. AOI = π/2 − π/N.
- **Realistic astigmatic Gaussian beam**: off-axis focal lengths
  `f_tan = R·cosθ/2`, `f_sag = R/(2cosθ)`, M²-corrected, propagated with the
  *actual* per-bounce AOI and chord lengths — tangential and sagittal radii
  evolve independently.
- Loss budget (reflectivity / clipping / aperture / hole truncation), isotropic
  and **per-plane astigmatic stability** (m_tan, m_sag), re-entrance score,
  volume utilisation, and spot-pattern diagnostics (distinct-spot separation,
  overlap, mirror fill fraction).
- Arbitrary launch: tangential & sagittal **start-spot offset** and two
  independent **launch tilts**.

**Tolerances (`tolerance.py`)** — the headline addition
- Per-mirror perturbations (decenter ×3, tilt ×2, ROC errors, aperture loss) and
  global perturbations (ring radius, height, launch position/tilt, reflectivity,
  wavelength), all truncated-normal.
- **Monte-Carlo** yield study with continuous walk-off metrics
  (`exit_drift_mrad`, `spot_walk_mm`) that don't suffer the step-function
  flatness of throughput.
- **One-at-a-time sensitivity** (mini-MC isolation) and an **RSS tolerance-budget
  allocator** with per-tolerance weighting.
- Presets: `loose` / `research_grade` / `flight_grade`; environmental factories
  for thermal (CTE-driven) and vibration studies.

**Visualisation (`viz3d.py`, `render.py`, `plots.py`)**
- Interactive 3-D cell view (Plotly): toroidal mirror meshes, the real ray path,
  bounce-coloured spots, a **real elliptical beam tube** swept along the path,
  input & exit rays.
- Per-mirror **spot constellations** (raytrace + ABCD/Lissajous prediction).
- **"As-built experiment" render**: gold mirror substrates, mounts, breadboard,
  entrance/exit holes, emissive laser beam, specular lighting.
- Matplotlib figures: spot pattern, astigmatic beam evolution, loss budget,
  static 3-D cell, Pareto front, MC histograms, sensitivity bars, tolerance
  budget, exit-pointing walk-off.

**Design exploration**
- `samplers.py` Sobol/LHS + Thorlabs catalogue snapping.
- `dataset.py` parallel Sobol dataset generator.
- `optimize.py` random + Bayesian (skopt) optimisation.
- `surrogate.py` RandomForest surrogate + permutation importance.
- `pareto.py` dependency-free multi-objective Pareto front.

**Validation (`validate.py`)**
- Analytic cross-checks (AOI = π/2 − π/N, chord length, spiral closure).
- ABCD-vs-raytrace residual.
- Optiland external cross-validation (soft-imported; skipped if absent).

---

## Quick start (CLI)

```bash
PY=./.venv/Scripts/python.exe

# one design, full physics report
$PY -m tmpc_platform_v5 simulate --N 12 --R_ring 60 --R_t 120 --R_s 180 \
    --chord_skip 5 --w0 0.5 --M2 1.1 --input_offset_z -2

# named design points
$PY -m tmpc_platform_v5 presets
$PY -m tmpc_platform_v5 simulate --preset longest_opl

# TOLERANCE STUDY (Monte-Carlo + sensitivity + RSS budget + plots)
$PY -m tmpc_platform_v5 tolerance --preset bo_best_one_inch \
    --tol-preset research --n-trials 300 --metric exit_drift_mrad \
    --delta-target 1.0 --out-dir results/tol

# INTERACTIVE 3-D + spot constellations (standalone HTML)
$PY -m tmpc_platform_v5 visualize --preset toroidal_lissajous --out-dir results/viz

# "AS-BUILT" experiment render
$PY -m tmpc_platform_v5 render --preset bo_best_one_inch --out results/render/exp.html

# physics validation (analytic + ABCD + Optiland if installed)
$PY -m tmpc_platform_v5 validate --N 8 --chord_skip 1

# multi-objective Pareto front
$PY -m tmpc_platform_v5 pareto --n 512 --objectives opl_m throughput --out results/pareto.csv

# design-space tools
$PY -m tmpc_platform_v5 dataset --n 2000 --thorlabs --family one_inch --out results/ds.csv
$PY -m tmpc_platform_v5 optimize --engine bayes --target opl_m --n-calls 60
$PY -m tmpc_platform_v5 surrogate --dataset results/ds.csv
$PY -m tmpc_platform_v5 sweep --param chord_skip --N 12
```

---

## Quick start (Python API)

```python
from tmpc_platform_v5 import TMPCConfig, simulate_tmpc, ToleranceSpec, full_report

cfg = TMPCConfig(N=12, R_ring=60, H=40, R_t=120, R_s=180,
                 chord_skip=5, w0=0.5, M2=1.1, input_offset_z=-2.0)
cfg.n_passes = 8 * cfg.N
res = simulate_tmpc(cfg)
print(res.bounces, res.opl*1e-3, res.throughput, res.stability_tan, res.stability_sag)

# full tolerance report (MC + sensitivity + budget)
rep = full_report(cfg, ToleranceSpec.research_grade(), n_trials=300,
                  metric="exit_drift_mrad")
print(rep["summary"]); print(rep["sensitivity"]); print(rep["budget"])
```

---

## Module layout

```
tmpc_platform_v5/
├── physics.py     toroidal surface, ray tracer, both topologies, simulate_tmpc, diagnostics
├── beam.py        astigmatic M² Gaussian beam, envelope-along-path (beam tube)
├── tolerance.py   perturbations, Monte-Carlo, sensitivity, RSS budget, thermal/vibration
├── samplers.py    Sobol/LHS + Thorlabs catalogue
├── dataset.py     parallel Sobol dataset generator
├── optimize.py    random + Bayesian optimisation
├── surrogate.py   RandomForest surrogate
├── pareto.py      dependency-free Pareto front
├── presets.py     named design points
├── plots.py       matplotlib figures
├── viz3d.py       interactive Plotly 3-D + spot constellations
├── render.py      "as-built" photoreal render
├── validate.py    analytic + ABCD + Optiland validation
├── summarise.py   text reports
├── cli.py         single entrypoint (subcommands)
└── tests/         pytest suite
```

All units are millimetres; wavelength in mm (1.654e-3 = 1654 nm); angles in
radians unless a name says `_deg`/`_mrad`. Optional deps (plotly, optiland,
scikit-optimize, scikit-learn) are soft-imported with clear messages.

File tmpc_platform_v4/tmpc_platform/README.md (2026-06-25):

# TMPC Optimisation Platform

Research-grade physics-informed optimisation platform for **Toroidal Multipass Cells (TMPC)** for laser absorption spectroscopy at 1.654 µm (CH₄ line).

This is the foundation you build on for the IITD-Abu Dhabi / Aston internship deliverable. It implements:

- Full 3D ray tracing on toroidal surfaces (exact reflection law, Newton-iterated quartic intersection)
- Gaussian beam propagation with separate tangential/sagittal ABCD matrices
- Loss budget: reflectivity, clipping, aperture truncation, hole truncation
- Chord-skip geometry (your v1 discovery, generalised)
- Stability and re-entrance analysis
- Sobol-sampled dataset generator (parallel, 1k–100k+ configs)
- 5 surrogate model families: RandomForest, XGBoost, LightGBM, GP, NeuralNet
- Physics-informed neural network (PyTorch) with monotonicity constraints
- Stacking ensemble meta-learner
- Bayesian optimisation (scikit-optimize) and NSGA-II multi-objective (pymoo)
- Active-learning loop (uncertainty-driven querying)
- SHAP explainability + Sobol global sensitivity indices
- Publication-grade plots (spot patterns, Pareto fronts, importance bars, beam evolution)

---

## Quick start

```bash
# 1. install deps (Windows PowerShell, in your .venv)
pip install -r requirements.txt
pip install streamlit plotly   # for the interactive viewers

# 2. one-shot full run (small for first try)
python -m tmpc_platform.scripts.run_all --n 500

# 3. full research run (slow; uses all cores)
python -m tmpc_platform.scripts.run_all --n 20000 --bo-calls 100 --ga-gen 60

# 4. printable physics summary of the best designs
python -m tmpc_platform.scripts.summarise_best --top 5

# 5. interactive dashboard (live sliders, opens in browser)
streamlit run app.py

# 6. Plotly notebook for paper figures
jupyter notebook notebooks/explore.ipynb
```

---

## Interactive viewers

### Streamlit dashboard — `streamlit run app.py`

Live sliders for N, R_ring, R_t, R_s, chord_skip, w0, wavelength, input tilt, etc. As you drag, the right pane updates:

- Top metric strip: bounces, OPL, throughput, vol. utilisation, max beam w, stability g², AOI mean, AOI max, chord length, clipped y/n
- Rotatable 3D bounce trajectory with colour-coded bounce index
- Per-bounce AOI line plot
- Tangential / sagittal beam radius evolution vs aperture limit
- Loss-mechanism bar chart (reflectivity / clipping / aperture / truncation)
- Full design summary table
- "Compare to dataset" panel: overlays the current config on the dataset OPL-vs-throughput scatter

Use this for design exploration: drag sliders, see how the spot pattern changes, see when the beam clips, see how chord_skip controls the AOI distribution.

### Plotly notebook — `notebooks/explore.ipynb`

Six paper-grade interactive figures, exportable to PDF/PNG via `kaleido`:

1. Rotatable 3D spot pattern of the best Pareto design
2. NSGA-II Pareto front 3D scatter (OPL × throughput × −clipping)
3. Dataset OPL vs throughput coverage, coloured by N, sized by vol. utilisation
4. Per-bounce AOI for the best config
5. Feature-importance bar charts (one per ML target)
6. OPL vs chord_skip sweep for N = 9, 12, 16 with coprime highlighting

### Best-design summary — `python -m tmpc_platform.scripts.summarise_best`

Prints a one-page physics report for the BO best + top-N Pareto configs:

```
========================================================================
  BAYESIAN-OPT BEST DESIGN
========================================================================
GEOMETRY     N=15   chord_skip=7   R_ring=75.9 mm   H=28.7 mm
MIRROR       R_t=130.4 mm   R_s=178.4 mm   aperture=8.6 mm   R=0.9990
BEAM         lambda=1654.0 nm   w0=1.398 mm   z_off=-2.50 mm

BOUNCES           120
OPL            18.082  m       (chord/bounce = 150.99 mm)
AOI mean         6.20  deg
AOI max          6.40  deg
Beam w_max      2.154  mm     (aperture 8.56 mm)
Vol. util.      18.15  %
Stability g²   0.0249        STABLE

LOSS BUDGET
  reflectivity loss  11.313 %
  clipping loss       0.000 %
  aperture loss       0.000 %
  truncation loss     9.985 %
  total throughput   79.832 %

AOI distribution: [text histogram]
```

---

Outputs land in `results/`:

```
results/
├── dataset.csv               <- 1 row per simulated configuration
├── models/                   <- joblib + pt files for every surrogate + ensemble + PINN
│   └── metrics.csv           <- R² and MAE per model & target
├── optim/
│   ├── bo_trace.csv          <- Bayesian opt iterations
│   ├── bo_best.csv           <- best config from BO
│   └── pareto.csv            <- non-dominated NSGA-II solutions
├── explain/
│   ├── shap_values__*.npy
│   ├── importance__*.csv
│   └── sobol_S1__*.csv
└── plots/                    <- all figures (.png)
```

---

## Run stages individually

```bash
python -m tmpc_platform.scripts.01_generate_dataset --n 5000 --workers 8
python -m tmpc_platform.scripts.02_train_models
python -m tmpc_platform.scripts.03_optimize --bo-calls 60 --ga-gen 40
python -m tmpc_platform.scripts.03_optimize --use-surrogate  # >100× faster
python -m tmpc_platform.scripts.04_explain
python -m tmpc_platform.scripts.05_visualize
```

---

## Use the simulator directly

```python
from tmpc_platform.physics_engine import TMPCConfig, simulate_tmpc

cfg = TMPCConfig(N=9, R_ring=50, H=40, R_t=100, R_s=100,
                 chord_skip=4, w0=0.5, n_passes=64)
res = simulate_tmpc(cfg)
print(f"OPL = {res.opl*1e-3:.2f} m   bounces = {res.bounces}   "
      f"throughput = {res.throughput:.3f}   "
      f"vol util = {res.volume_utilisation:.2f}")
```

## Use a trained surrogate

```python
import joblib, numpy as np
from tmpc_platform.ml_models.training import FEATURES

model = joblib.load("results/models/RandomForest__opl_m.joblib")
X = np.array([[12, 60, 40, 120, 110, 3, 0.4, 0.999]])  # FEATURES order
print("predicted OPL [m]:", model.predict(X)[0])
```

## Multi-objective optimisation example

```python
from tmpc_platform.optimization import nsga2_optimize
from tmpc_platform.scripts.optimize_helpers import sim_obj

res = nsga2_optimize(
    objectives=[lambda c: sim_obj(c, "opl_m"),
                lambda c: sim_obj(c, "throughput"),
                lambda c: sim_obj(c, "clipping")],
    pop_size=60, n_gen=40,
    maximize_flags=[True, True, True],
)
print(res["pareto"].head())
```

---

## Architecture

```
tmpc_platform/
├── physics_engine/        toroidal surfaces, ray tracer, Gaussian beam, losses, stability
├── dataset_generation/    Sobol / LHS samplers, parallel evaluator
├── ml_models/             surrogates, PINN, stacking ensemble, training helpers
├── optimization/          Bayesian opt, GA / NSGA-II, active learning
├── explainability/        SHAP, Sobol sensitivity indices
├── visualization/         all plots (saved as PNGs)
├── scripts/               01–05 stage scripts + run_all
├── tests/                 pytest smoke tests
├── configs/               YAML configs
└── results/               outputs land here
```

---

## Validation hooks (what to add next)

The platform is built so you can plug in higher-fidelity validators as you go:

1. **Optiland comparison** — wrap an `optiland`-based simulator with the same `TMPCConfig` interface and run it on a small subset of the dataset for ground-truth comparison. Drop the wrapper into `physics_engine/validators.py`.
2. **Zemax / 3DOptix export** — emit `.zos` or `.optix` from a `TMPCConfig`. Useful for the conference paper figures.
3. **Thorlabs mirror catalogue** — restrict R_t, R_s, aperture to discrete Thorlabs SKUs by adding a discrete-search wrapper around the optimiser.
4. **Drone vibration analysis** — add a `mechanical/vibration.py` module that applies random per-mirror tilt jitter and recomputes throughput vs. RMS tilt angle. This feeds the noise-floor analysis the brief asks for.
5. **CAD export** — emit Fusion 360 parameter tables (CSV) from the Pareto front so CAD work tracks the optimisation directly.

---

## Notes on physics fidelity

- The toroidal surface uses the exact implicit equation `(√((R_t-z)² + x²) - (R_t-R_s))² + y² = R_s²` with analytic gradient; ray intersection is found by Newton iteration from a paraxial seed. This is accurate for small angles and converges in ≤5 iterations for the regime of interest.
- Gaussian beam propagation is ABCD-matrix-based, separately in tangential and sagittal planes — the standard treatment for astigmatic toroidal optics.
- Loss budget combines reflectivity, hard clipping (`w_max ≥ aperture`), soft Gaussian truncation, and entrance/exit hole truncation.
- The default `n_passes = 8N` matches your Tuzson/Graf baseline.
- Stability is computed from the symmetric ring g-product `(1 - chord/R_t)²`.
- Re-entrance score = `period(N, chord_skip) / N` ∈ (0, 1], maximal when `gcd(N, chord_skip) = 1`.

## Notes on ML

- Targets: OPL [m], throughput, quality (composite), stability_g.
- Train/test split is fixed seed for reproducibility.
- The PINN adds a monotonicity penalty: more bounces ⇒ longer OPL ⇒ lower throughput. This regularises predictions in low-density regions of the design space.
- Stacking ensemble is a Ridge meta-learner over all base predictions for a target.

---

## Reproducing the conference paper plots

After `run_all`, look in `results/plots/` for:

- `spot_pattern_best.png` — the best Pareto config's 3-D bounce trace and unfolded pattern
- `roc_vs_opl.png` — OPL vs tangential ROC, coloured by throughput
- `stability_landscape.png` — g² stability across (R_t, R_ring)
- `beam_evolution.png` — tangential and sagittal beam radii over the cell
- `pareto_front.png` — non-dominated OPL × throughput × −clipping front
- `metrics_table.png` — surrogate model comparison
- `importance__*.png` — SHAP / permutation feature importance

---

## License & IP

Per IITD-Abu Dhabi / Aston joint brief, all IP belongs to Aston. Internal use only.

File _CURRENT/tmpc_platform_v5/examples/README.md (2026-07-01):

# TMPC Platform v5 — figure gallery

Example outputs from `tmpc_platform_v5`, for two showcase designs:

- **`bo_best_one_inch`** — a realistic Bayesian-optimised cell built from
  off-the-shelf Thorlabs 1" gold mirrors (N=10, R_ring≈63 mm, chord_skip=7,
  R=0.98): **80 bounces, 8.16 m path, 19.7 % throughput**.
- **`toroidal_lissajous`** — a toroidal (R_t≠R_s) long-path design showing the
  astigmatic Lissajous spot pattern: **128 bounces, 29.9 m path**.

All figures are regenerated with:

```bash
./.venv/Scripts/python.exe -m tmpc_platform_v5.examples.generate_gallery
```

Interactive `.html` versions (rotate/zoom in a browser) sit next to every PNG.

---

## 1. 3-D cell view — real ray path + beam tube

The true ray-traced path with the astigmatic Gaussian beam rendered as a tube,
mirror surfaces, and the input/exit rays.
[interactive](figures/bo_best_one_inch_cell3d.html)

3D cell view

## 2. "As-built" experiment render

Photoreal view: gold 1" substrates, mounts, breadboard, entrance/exit hole,
and the laser beam bouncing through the cell.
[interactive](figures/bo_best_one_inch_experiment.html)

As-built render

## 3. Per-mirror spot constellations

Where the beam lands on each mirror face (coloured by visit order), inside the
clear aperture. The toroidal design shows the characteristic Lissajous spread.
[interactive: bo_best](figures/bo_best_one_inch_constellations.html) ·
[interactive: toroidal](figures/toroidal_lissajous_constellations.html)

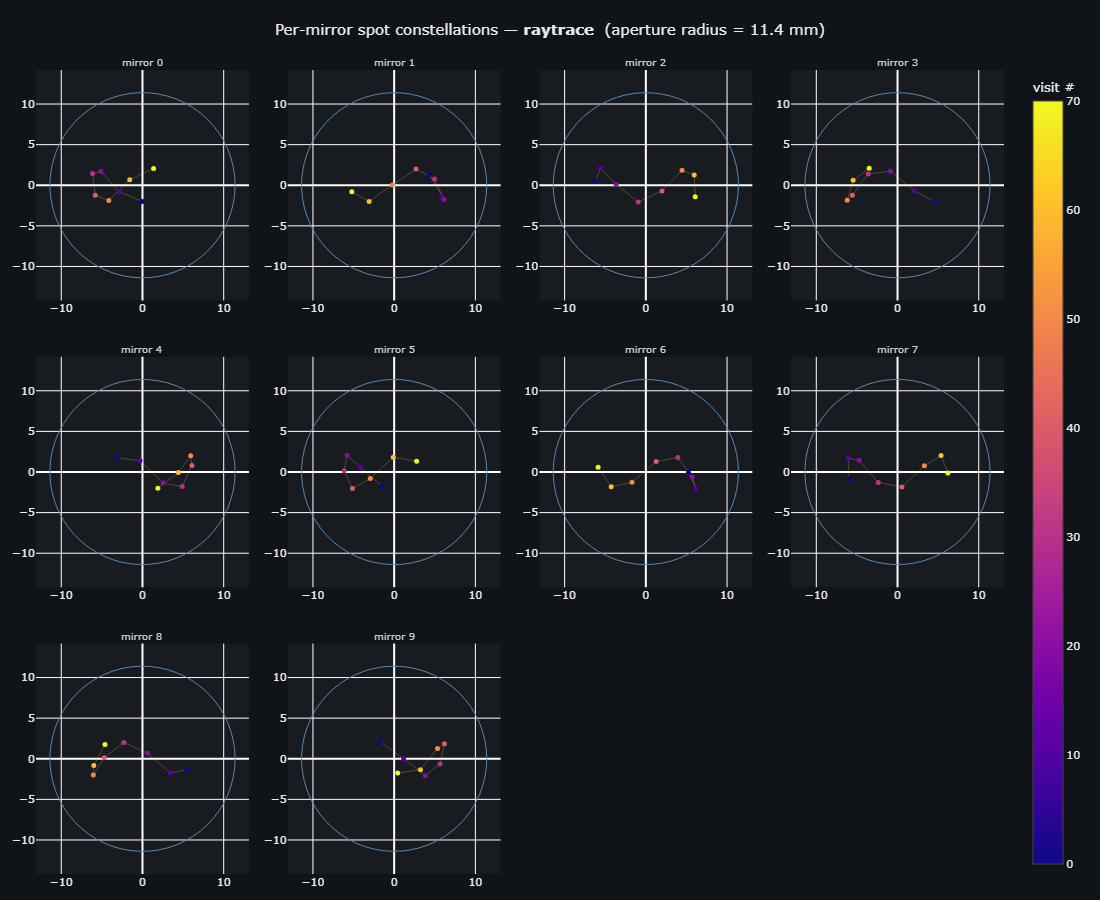
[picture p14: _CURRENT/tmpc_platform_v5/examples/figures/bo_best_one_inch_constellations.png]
Spot constellations (bo_best)

Spot constellations (toroidal Lissajous)

## 4. Beam evolution (astigmatic) & loss budget

Tangential vs sagittal 1/e² radius through the cell (they differ because of
off-axis astigmatism), against the clear aperture; and the loss breakdown.

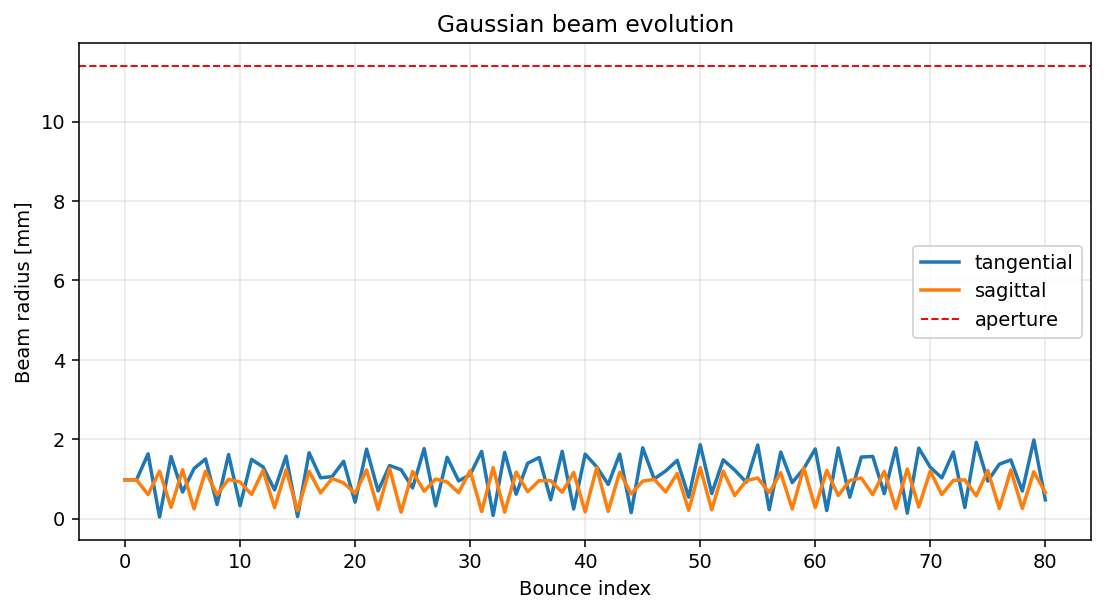
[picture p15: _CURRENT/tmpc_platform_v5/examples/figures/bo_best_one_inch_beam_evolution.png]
Beam evolution

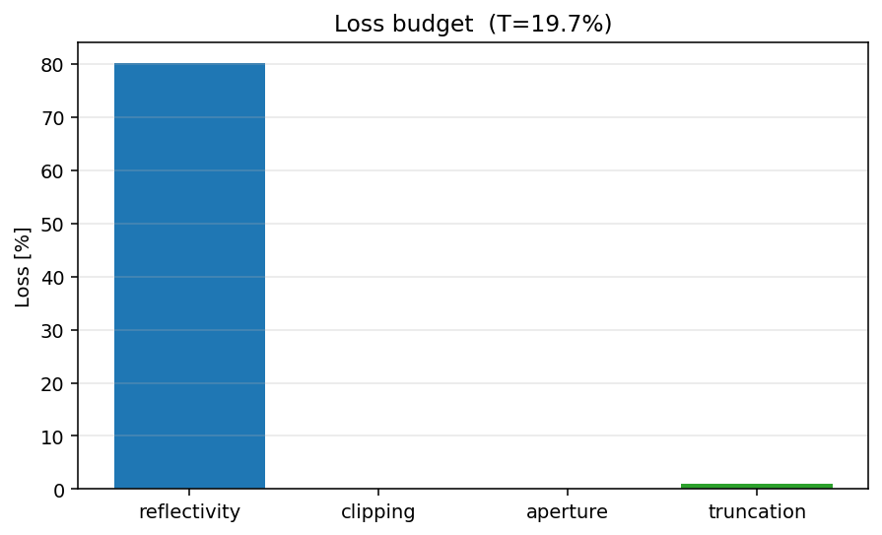
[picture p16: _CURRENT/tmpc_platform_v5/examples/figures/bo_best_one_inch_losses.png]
Loss budget


## 5. Spot pattern (matplotlib) & static 3-D

Browser-free publication figures.

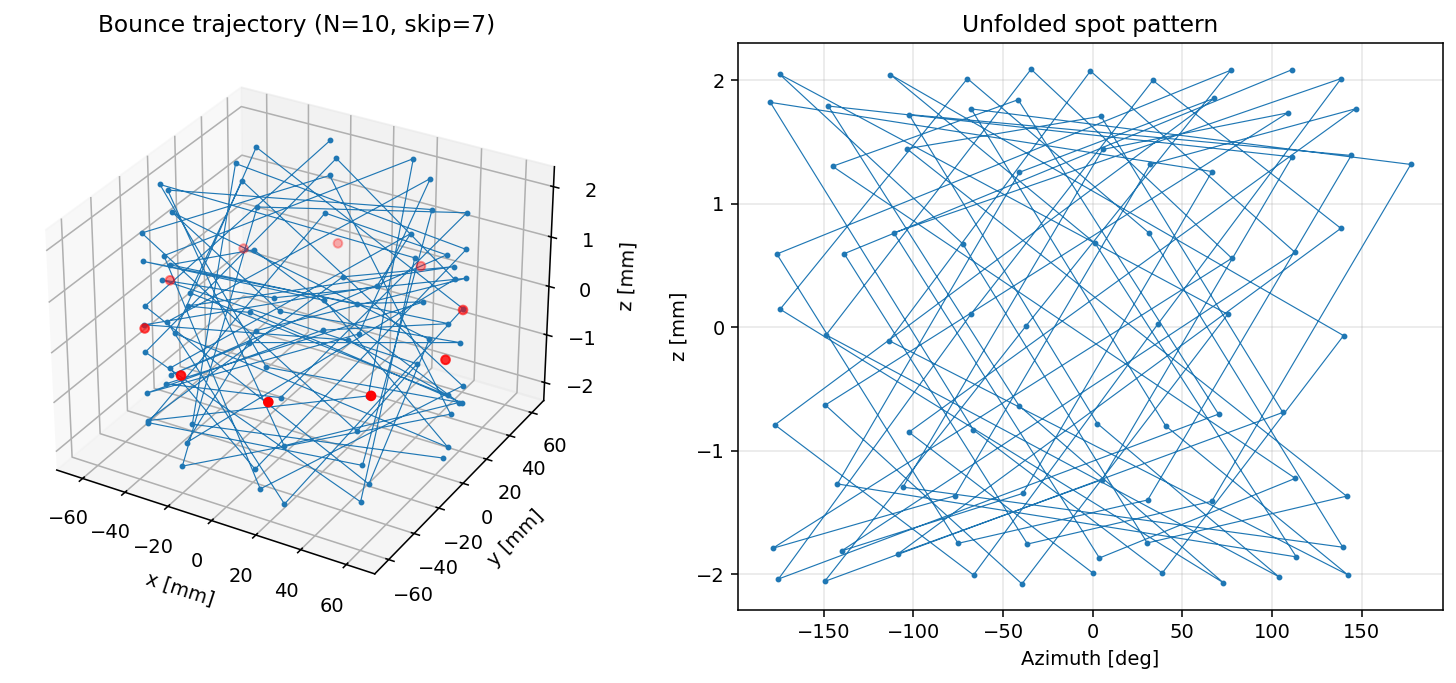
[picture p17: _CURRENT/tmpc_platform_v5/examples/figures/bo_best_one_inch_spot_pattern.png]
Spot pattern

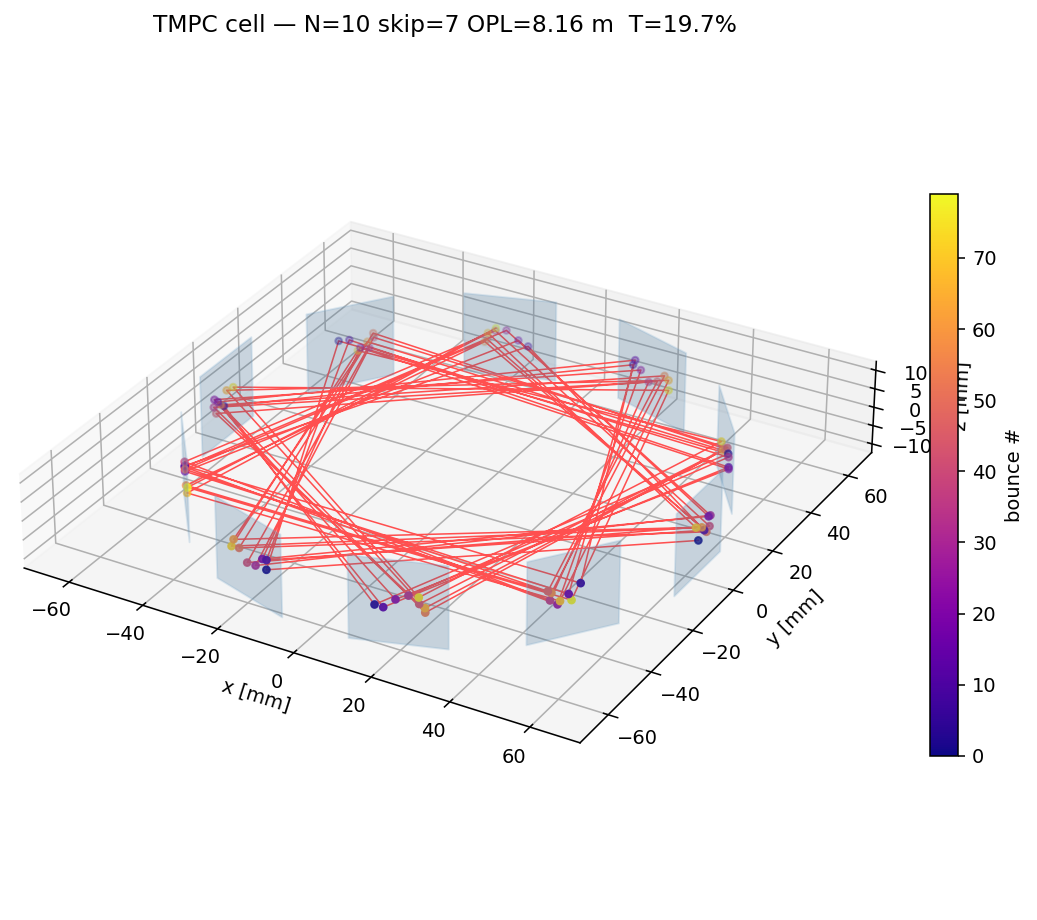
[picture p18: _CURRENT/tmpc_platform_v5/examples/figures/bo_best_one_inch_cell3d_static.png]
Static 3D cell


---

## 6. Tolerance analysis (`bo_best_one_inch`, 200-trial Monte-Carlo)

**Sensitivity** — which fabrication/alignment errors dominate the exit-beam
pointing (per-mirror decenter and tilt lead, as expected for an 80-bounce cell):

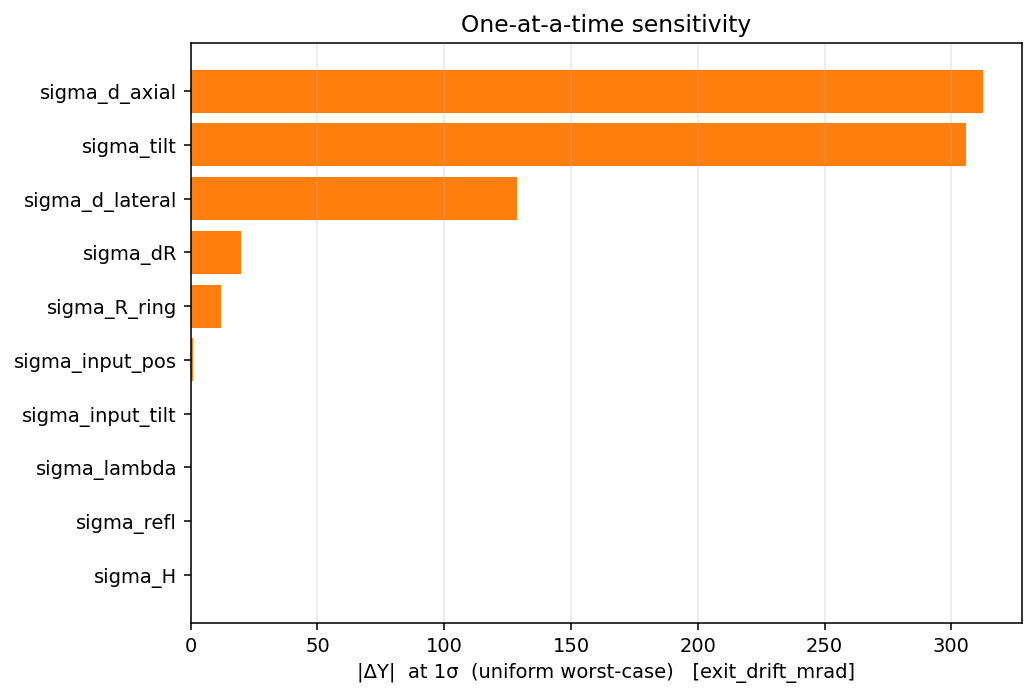
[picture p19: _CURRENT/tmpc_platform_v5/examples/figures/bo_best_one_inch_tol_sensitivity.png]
Sensitivity


**RSS tolerance budget** — the per-tolerance 1σ you can afford to hold exit
pointing within target:

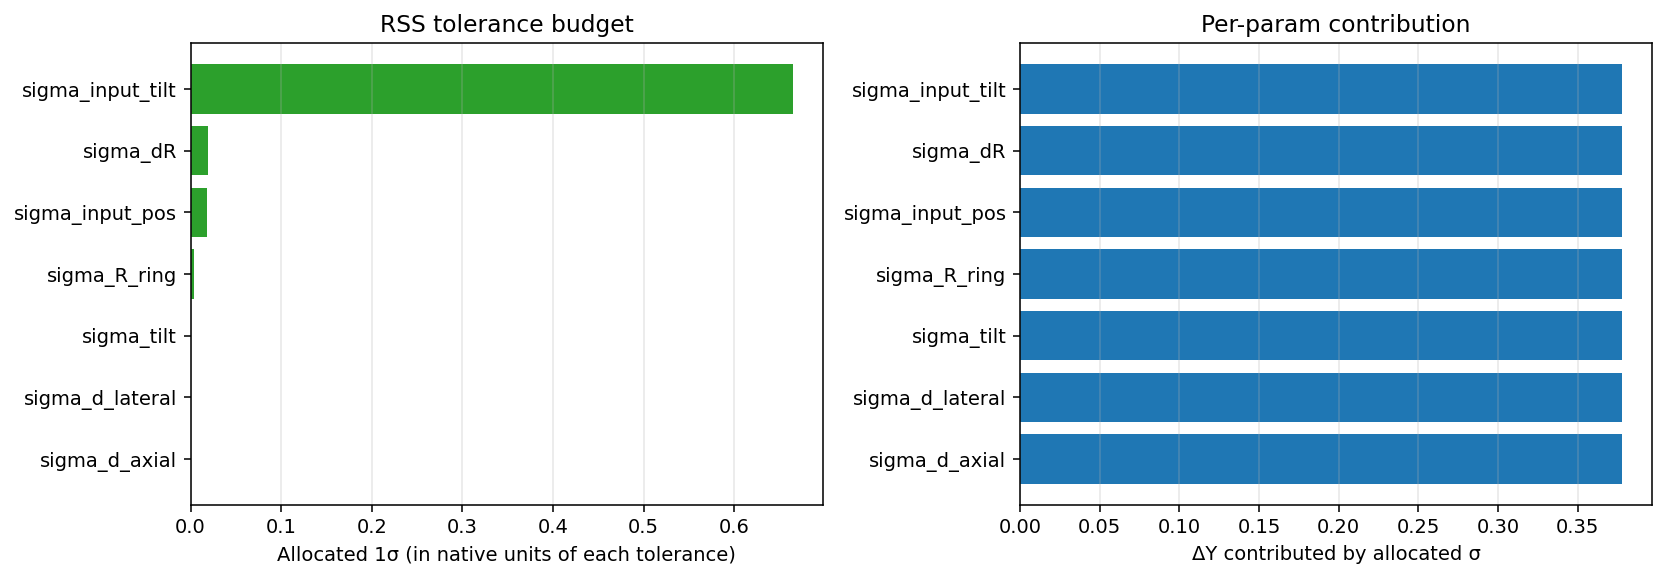
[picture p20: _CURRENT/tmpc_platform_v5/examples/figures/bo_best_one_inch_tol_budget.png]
Tolerance budget


**Monte-Carlo distributions** and **alignment walk-off**:

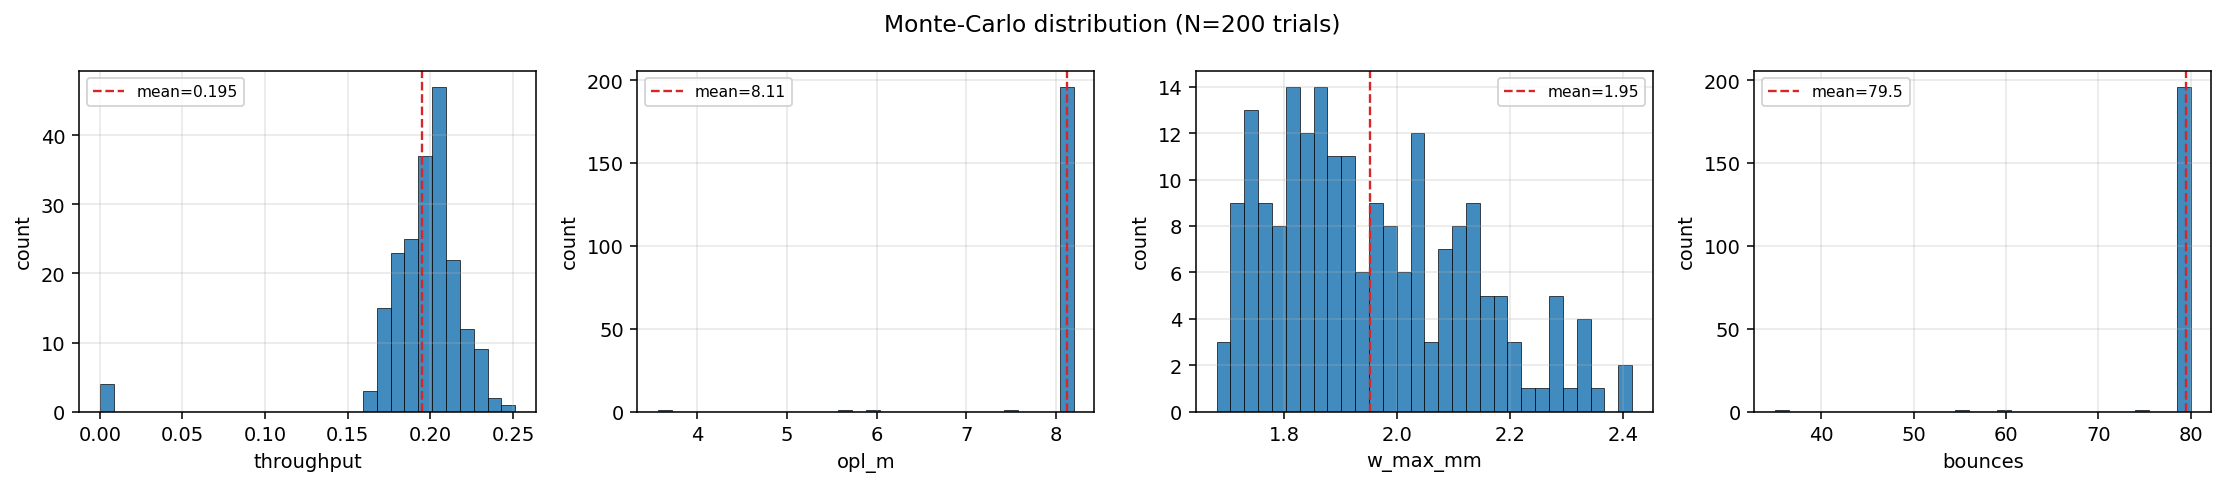
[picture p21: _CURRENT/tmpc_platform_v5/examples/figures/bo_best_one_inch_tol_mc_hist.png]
MC histograms

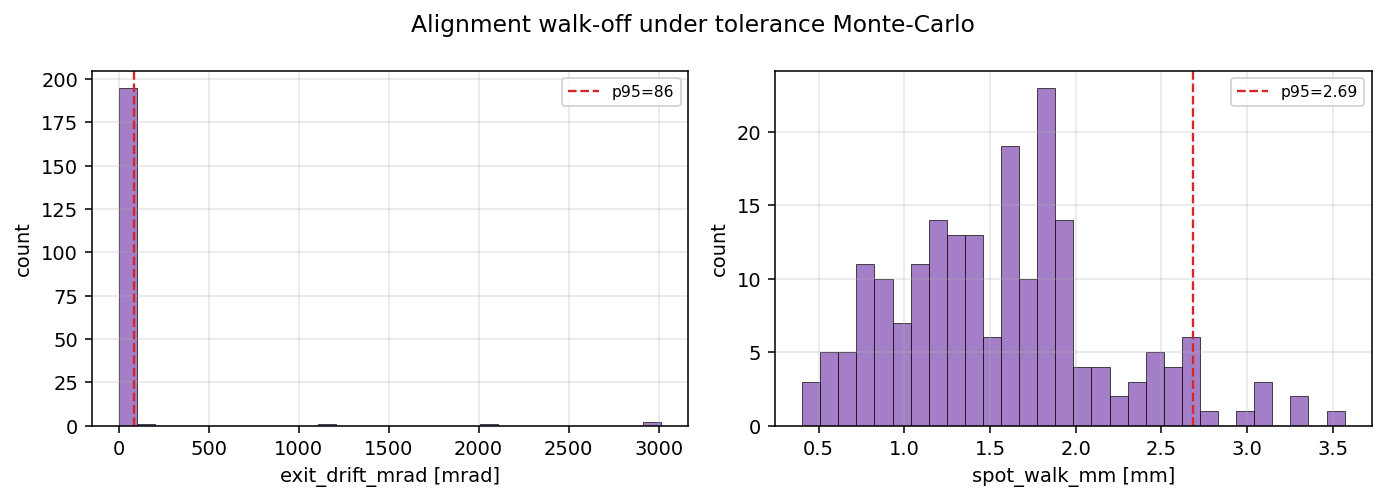
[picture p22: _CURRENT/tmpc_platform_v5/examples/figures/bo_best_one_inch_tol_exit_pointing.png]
Exit pointing


---

## 7. Multi-objective Pareto front

Non-dominated designs trading optical path length against throughput
(dependency-free dominance filter over a Sobol batch):

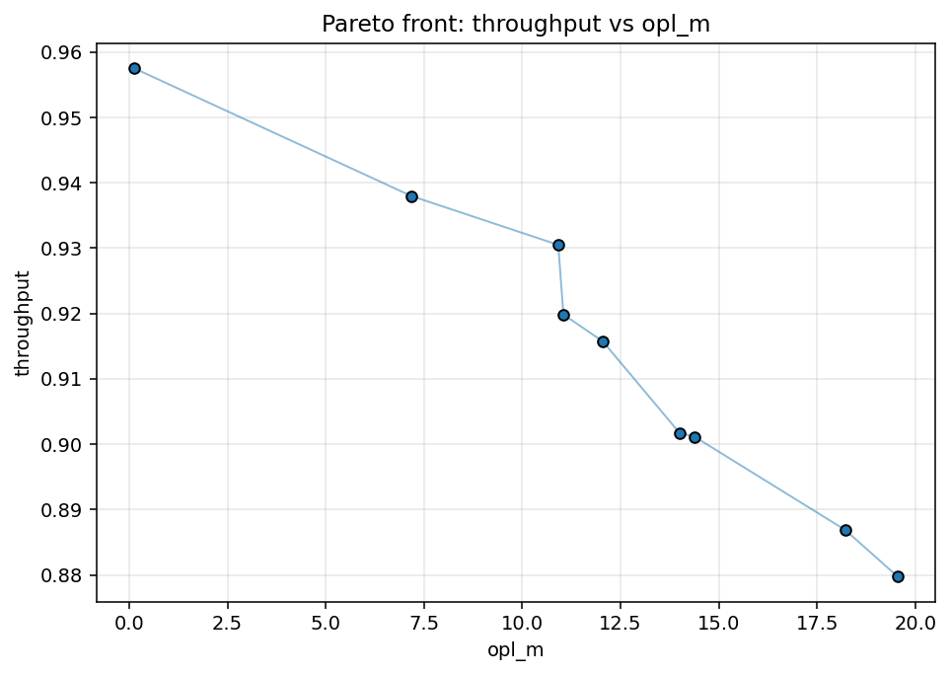
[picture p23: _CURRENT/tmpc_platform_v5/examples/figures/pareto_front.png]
Pareto front


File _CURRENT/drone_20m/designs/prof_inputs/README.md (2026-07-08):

# Dr. Benoy's tolerance-framework documents (2026-07-08)

*(Five .docx attachments from the "Draft paper of Sumant (Toroidal cell)" and
"Final algorithm" email threads, Thomas.Benoy@warwick.ac.uk → Sumant, cc Naman
Rindani + Ayachi Mishra. Full extracted text in this folder, one .txt per
document. Originals in Sumant's mailbox / `C:\Users\ASUS\Downloads\*.docx`.)*

## The five documents

| file | sent | covering note |
|---|---|---|
| `multipass_gas_cell_tolerance_analysis_alignment_regimes` | 08 Jul 01:04 | "Check this for each of your designs." |
| `multipass_gas_cell_tolerance_analysis_post_alignment_drift` | 08 Jul 17:16 | "You can mitigate manufacturing tolerance by alignment to some extent. So be careful when you present this in your papers." + find a generic low-cost 3D-printable plastic/PEEK design; pick one material combination for drone; no Ti/Invar (expensive), aluminium reasonable. |
| `multipass_gas_cell_full_integrated_comparison` | 08 Jul 20:00 ("Final algorithm") | "Try to include this model into your papers. Basically, for an input spot pattern drift or angle drift in the beam exits the second mirror hole with decent clearance it's good !! This is what you have also modelled I assume." |
| `multipass_gas_cell_tolerance_ieee_style_paper` | 08 Jul 20:11 | "This is same as before but in paper format. Adapt this justification into your papers." |
| `comsol_ray_tracing_validation_protocol_mirror_only` | 08 Jul 20:52 | "This is the final comsol ray tracing validation protocol you need to implement to validate your drone ray tracing model. No need experiment. This will easily be a paper. No need to model the cell body." |

All five are written for the two-concave-mirror Herriott geometry at L = 300 mm,
but the covering notes instruct us to apply the *framework* to every toroidal
design and adapt the justification into our paper.

## The framework (his "final algorithm")

Three-tier error budget, six-DOF vectors `v = [dx,dy,dz,dθx,dθy,dθz]`:

1. **Construction tolerance** = manufacturing/fixing accuracy `C_build`.
   **Recoverable by alignment** if within the alignment capture range → it is a
   *capture-range / build-feasibility check*, NOT part of final in-use drift.
2. **Alignment tolerance** = residual after the user aligns, `R_align =
   F_resolution × F_ease × F_user × F_feedback`. Three regimes (Easy = monolithic
   /dowel-pinned + visible feedback; Medium = lockable cartridge/shimmed; Hard =
   free-space folding mirrors / blind). COMSOL-sweep residual vectors (Table III
   of the protocol): Easy 0.02 mm / 0.05 mrad, Medium 0.05 mm / 0.15 mrad, Hard
   0.12 mm / 0.40 mrad (dx / dθx,y per axis).
3. **Operational drift** `D_op` = post-alignment thermal + vibration + pressure +
   thermal-cycling. **This is the dominant real in-use tolerance.**

Final in-use vector `T = R_align + D_op` (construction excluded when
recoverable). Metrics kept separate: `Pxy = √(dx²+dy²)` (mm),
`Θxy = √(dθx²+dθy²)` (mrad); combined only for clearance checks:
`X_combined = Pxy + L·Θxy` (0.3·Θ at L = 300 mm). Acceptance = the beam still
exits the exit hole with decent clearance under input spot/angle drift.

**Destination envelopes** (max total drift the design must accommodate;
ordered drone > field > lab because environment dominates):
lab 0.20 mm / 0.67 mrad · field 0.35 mm / 1.17 mrad · drone 0.60 mm / 2.0 mrad
(equivalent input spot at L = 300 mm — for our cells convert via our own
launch-to-exit sensitivity, not the 0.3 factor).

**Drone operational-drift vectors he assigns per mount architecture**
(max post-alignment, drone row, protocol Table VI — these are directly
comparable to our Monte-Carlo σ's):

| architecture | dx,dy (mm) | dz (mm) | dθx,y (mrad) | combined spot (mm) |
|---|---|---|---|---|
| Al isostatic flexure | 0.050 | 0.080 | 0.15 | 0.134 |
| Ti flexure cartridge | 0.045 | 0.070 | 0.13 | 0.119 |
| Invar insert | 0.040 | 0.060 | 0.10 | 0.099 |
| Hybrid plastic body + Al mirror cartridge | 0.120 | 0.180 | 0.40 | 0.339 |
| Injection-moulded + inserts | 0.250 | 0.350 | 1.00 | 0.778 |
| CNC PEEK/Delrin | 0.300 | 0.400 | 1.20 | 0.933 |
| 3D-printed plastic (PA12/PLA) | 0.700 | 0.900 | 3.00 | 2.263 |
| Bosch rail / O-ring datum / ext. kinematic | — | — | — | not recommended |

**COMSOL protocol** (10 steps): mirror-only model (Ray Optics Module, specular
mirrors + aperture/hole masks, no cell body), nominal trace → input sweeps
(x_in, y_in, θx, θy) → capture-range check with C_build → apply R_align regime →
apply D_op vectors per environment/material → per-DOF worst-case sweeps →
Monte-Carlo (250 screen / 1000–5000 final) → pass/fail. **Yield thresholds:
>99 % lab, >99.5 % field, >99.9 % drone.** Run-log template given (Table VII).
Materials/CTE table supplied (Al 23, SS 16, Ti 8.6, Invar 1.5, PEEK 45–50,
PA12 100–160 ppm/K; EPO-TEK 353ND three-dot bonding only; O-ring = seal only).

## What this changes for the TMPC paper (mapping to our assets)

1. **Reframe our construction-tolerance section.** Our process-grade MC treats
   as-built error as final — in his framework that is the *zero-adjustment
   lower bound* plus a *capture-range check*, and the honest headline in-use
   number is `R_align + D_op`. Our "flight-grade" MC σ's (0.05 mm / 0.1–0.2
   mrad) sit almost exactly on his drone Al-flexure drift vector — cite his
   envelope table as the source and add the (small) pressure + cycling terms.
   Present per design: (a) works-as-built grade (no alignment, our current MC),
   (b) capture-range check vs alignment regime, (c) in-use robustness under
   `R_align + D_op`. His caution "manufacturing tolerance can be mitigated by
   alignment — be careful how you present this" is aimed exactly at claims like
   "fails at FDM grade": FDM *construction* is recoverable by one alignment
   session; it is FDM *operational drift* (creep/CTE) that kills drone use.
2. **Input-drift capture envelope per design** ("check this for each of your
   designs"): compute max input spot offset and max input angle drift that
   still exits the hole with clearance — one number pair per design vs his
   destination envelopes. Our launch-drift MC already samples this; a dedicated
   per-DOF sweep makes it a table/figure his model asks for.
3. **99.9 % drone yield**: re-run flagship MC at 5000 trials (400-trial runs
   cannot resolve 99.9 %).
4. **Materials decision** (his explicit ask): one combination for drone =
   **aluminium body + aluminium isostatic-flexure mirror seats** (no Ti/Invar —
   expensive); low-cost route = **hybrid plastic (PA12/PEEK) outer body +
   aluminium mirror-cartridge ring**; all-plastic datum only for lab/prototype.
   Our Ø182 two-inch N=8 sparse design is the natural "generic low-cost
   3D-printable" candidate — largest clearances in the menu; verify it against
   the hybrid drift vector (0.12 mm / 0.40 mrad).
5. **COMSOL validation package** replaces the lab experiment for the
   ray-tracing-validation paper ("No need experiment... easily be a paper"):
   port the 10-step protocol to the toroidal N-mirror ring (our
   `MirrorPerturbation` machinery already implements every step natively),
   prepare COMSOL parameter tables + comparison harness (import COMSOL spot
   CSV → diff vs our tracer, like the Optiland cross-check at 0.000 µm).
6. **Author list resolved**: Varanasi¹, Benoy²(co-first,*), **Naman Shreyas
   Rindani¹, Ayachi Padmanabh Mishra¹**, Lennox³ (Eblana Photonics), Rebrov²
   (Warwick). Benoy now writes from Warwick — affiliation² set to Warwick,
   department to confirm (was Aston).
7. **Timeline** (from the 07-07 review mail): three papers by end of July,
   Q1-journal target; Warwick lab window 21–31 July still reserved for spot-
   pattern validation via the components-ordering thread (kinematic mounts,
   fibre source available; we supply mirrors + mounts) — but the COMSOL route
   supersedes the *need* for experiment in the validation paper.

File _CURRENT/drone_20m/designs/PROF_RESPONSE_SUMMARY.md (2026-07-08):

# Response map — Dr. Benoy's review points → deliverables

*(One page for the reply email. Every number is exact-trace and/or
Monte-Carlo verified; files live in `_CURRENT/drone_20m/designs/`.)*

| Your point | Answer in one line | Where |
|---|---|---|
| "Compare against the IRSweep gas cell... what is the downside?" | IRcell-S15: 15.12 m / Ø194 / 128 mL; ours: 20.38 m / Ø180 (+35 % path, smaller disc, 86.7 % verified throughput, catalog mirrors). Honest downside: our sealed volume is 200–330 mL vs their 31–128 mL — chord-skip sweeps the whole disc; per-litre we match the toroidal family with 2–5× the path. | [irsweep_comparison.md](irsweep_comparison.md) |
| "Compare overlap factor... Are your beams overlapping?" | No. Worst same-mirror pair sits 2.8–5.8 beam radii apart → field coupling −34…−148 dB (exact, all pairs, all designs). We propose the graded d/w̄ criterion as a figure of merit — the literature only has the binary rule. IRcell-4M superposes beams by design (hence its Teflon mask); IRcell-S segment edge sits at 3.45 w — our designs straddle-to-beat that. | [irsweep_comparison.md §3](irsweep_comparison.md) + `figures/overlap_coupling.png` |
| "Will the OD noise be worse?" | Mechanism-by-mechanism: no mask, no beam superposition, hole ≥2× beam dia (McManus criterion), wedged windows (23× measured suppression precedent), polished catalog mirrors (no diamond-turning tool marks — Graf's residual fringe source). Expected NEA in the segmented-cell class (2×10⁻⁵), i.e. better than masked toroids. Chord-parasite FSRs (0.034–0.064 cm⁻¹) sit ON the H₂ linewidth, which is exactly why the separation margin matters — quantified. | [irsweep_comparison.md §4](irsweep_comparison.md), [multigas.md §3b](multigas.md) |
| "Compare with other works also" | Full table: Tuzson 2013 toroid, Graf 2018 SC-MPC (page 2434 — 2665 is a typo worth fixing in our sources), Chang 2020 multi-layer, IRcell family, Aerodyne benchmark. | [irsweep_comparison.md §2](irsweep_comparison.md) |
| "Do for hydrogen 2121.8 nm and ammonia 1512.2 nm" | Geometry is λ-independent (spots scale √λ). NH₃: entire menu robust as-built. H₂ (hardest case): six designs robust; dedicated searches raised the tri-gas ceiling to **25.72 m/Ø185** (doubly confirmed). LODs @20 m, 10⁻⁴ NEA: CH₄ 129 ppb, NH₃ 92 ppb, H₂ 0.17–0.31 %v (≈5 % LEL — a usable leak alarm; tens of ppm with WMS at 10⁻⁶). Lasers/detectors specced per gas. Note: our 1653.7 nm line is 2ν₃ R(3), not R(4). | [multigas.md](multigas.md), `figures/trigas_matrix.png` |
| "Compare the volume of the disc... toroidal cells are supposed to be low volume" | Dedicated half-inch (CM127) family: flight-robust 7.54 m/Ø122/**40 mL** (PVR 190 m/L) and — with a 0.8 mm collimator (decision needed) — **9.11 m/Ø129/75 mL at 90.8 %** (2.3× IRcell-S4 path). Active-tier showcase: 19.3 m/Ø93/**37 mL** = PVR 518 m/L (4× best commercial). Gas exchange 1–9 s pumped, ~25 ms open-flow. | [low_volume_menu.md](low_volume_menu.md), `figures/volume_pvr_comparison.png` |
| "Choose the cell window... CaF₂ is too brittle... wedged and angled" | **WW10530-C** (Ø1/2″ UVFS wedged, AR 1050–1700 nm) for NH₃+CH₄; **WW30530-D** (Ø1/2″ **sapphire** wedged, AR 1.65–3.0 µm) for CH₄+H₂. Sapphire vs CaF₂: ~10× hardness, ~12–19× rupture strength, ~4–6× fracture toughness. 30 arcmin wedge + 3–5° mount: ghost walk-off ≈30× beam divergence; residual FSR ~1 cm⁻¹ = fittable baseline. | [window_selection.md](window_selection.md) |
| "Holed mirrors vs entry/exit from sides" | The hole is a transverse-selective aperture; a side slot selects only azimuth and leaks the beam at its first return (N chords). Side entry caps the Ø180 ring at 2.3 m; the hole is worth exactly k = 9–19×. Side gaps are geometrically available (1.7–12.7 mm) — the objection is optical, not mechanical. | [entry_exit_comparison.md](entry_exit_comparison.md) |
| "Design in Fusion 360... 3D printing or CNC... weight and vibration... construction tolerance... $200 printed cell" | Parametric CAD (STEP for Fusion 360 + STL) generated from the verified design rows for 4 housings. Process-mapped Monte-Carlo: dense designs need precision CNC; the sparse 20.4 m/15.3 m designs complete 100 % even on standard CNC / printed+machined seats (one trim). A fully printed cell fails three ways (accuracy, CTE+moisture, lid modes 330–670 Hz inside the rotor band) — and one-off CNC Al costs the same as a good print ($250–600). Masses 0.9–1.3 kg pocketed; Al lid modes 1.2–2 kHz (above band); dampers outside + rigid inside per the flight-proven Empa result. | [manufacturing.md](manufacturing.md), [cad/](cad/), `figures/construction_tolerance.png` |
| (implied) "will it survive operation?" | Vibration-to-signal budget (elastic ring tilt 0.01–0.1 µrad/g, margin >10³ — coupling is via launch/detector chain, mitigated in the CAD), polarization audit (launch sagittal: 96–99.9 % eigenaxis purity; no analyzers after the cell), thermal windows ±18–30 K with the trim heater as anti-dew, contamination self-monitoring via T = R^(n−1). | [operational_audit.md](operational_audit.md), [active_tier_requirements.md](active_tier_requirements.md) |

**New results since the draft you read** (all verified): tri-gas ceiling
25.72 m/Ø185; 15.30 m/Ø175 at 89.5 % with 7 spots/mirror (the
budget-build corner); half-inch low-volume family down to 37–75 mL;
converged robust frontier (deeper searches add nothing — the menu is the
architecture's true boundary); mixed-SKU rings (two alternating catalog
ROCs) close re-entrant patterns to nominal 60–69 m in the same envelope,
including combinations where *neither* uniform ROC closes — spot-crowding
currently keeps them at the active/experimental tier (study in
progress).

**Two decisions requested:** (1) the 0.8 mm collimator for the half-inch
mini family (the 1″ menu keeps the 1.3 mm standard); (2) confirm author
list ordering for the revision: S. Varanasi, T. Benoy (co-first), [two
team members], R. Lennox, E. Rebrov.

---

# Round 2 — the five tolerance-framework documents (2026-07-08) → deliverables

*(Source docs archived in [prof_inputs/](prof_inputs/). Everything below
is executed, exact-trace/Monte-Carlo verified, and in paper v2.3.)*

| Your directive | Answer in one line | Where |
|---|---|---|
| "Construction tolerance can be mitigated by alignment — be careful how you present this" | Reframed as the three-tier chain: C_build = capture-range check (recoverable), R_align = residual, D_op = post-alignment drift (the real in-use tolerance). Paper §2.8 states the chain, §6.1/6.4 report as-built survival explicitly as the strictest zero-adjustment reading with the robust vs robust-after-trim tiers separated. | paper §2.8, §6.3–6.4 |
| "Final algorithm: input spot/angle drift must still exit the hole with decent clearance — check this for each of your designs" | Executed per design by per-DOF bisection: capture envelopes 0.37–1.14 mm position, 3.0–18.8 mrad angle — ≥2.2×/5.5× beyond the summed easy+Al-flexure and medium+hybrid drone demand for every menu design. Angle capture is 1–2 orders above demand (re-entrance tolerates tilt; position drift moves the pattern ~1:1 toward the rim). | [capture_envelope.md](capture_envelope.md), paper §6.3 + Fig. 13 |
| MC yield > 99.9 % for drone/product | 5000-trial composed-vector MC (uniform inside R_align + D_op, per mirror + launch chain): tri-gas 25.7 m, sparse 15.3 m and two-inch 19.0 m pass 5000/5000 (Wilson LB 99.92 %) on the Al-flexure architecture; H2/mini/compact at field grade 99.3–99.7 %; boundary designs 92–96 % (as expected of ceilings). | [mc5000_drone_yield.csv](mc5000_drone_yield.csv), paper §6.3 Table 9 |
| "Choose one material combination for drone; no Ti/Invar; aluminium reasonable" | **Aluminium 6061 monolithic ring** (drone baseline) — meets the product criterion without exotic metals; the one soft axis (common-mode ring-radius drift) is the thermal mode, governed by trim law + thermal window, not by CTE upgrades. | [materials_decision.md](materials_decision.md) |
| "Generic low-cost design capable of 3D printing with plastic/PEEK" | **Hybrid printed shell + machined Al mirror cartridge** (plastic never defines an optical datum): 33–46 % structure-mass saving, 6 mm CF-PA12 lids ≥674 Hz, carried best by the sparse two-inch 19.0 m design at 95.0 % hybrid drone yield (research grade; product grade in plastic needs CF drift or a relaxed-clearance generation). CAD shipped for hybrid 19m-2inch + 14 cm. | [materials_decision.md](materials_decision.md), [hybrid_materials.csv](hybrid_materials.csv), [cad/](cad/) |
| "Implement the COMSOL ray-tracing validation protocol — no experiment needed; this will easily be a paper" | Full package shipped: per-design mirror/launch geometry CSVs in platform coordinates, perturbation envelopes, the protocol's step-7 worst-case run log executed natively (333 runs — reference answer sheet for COMSOL to reproduce), and a chief-ray comparison harness with the same <10 µm criterion the Optiland cross-check met at 0.000 µm. Worst-case finding: the only recurring coherent failure is d_ax = uniform ring-radius shift = the thermal breathing mode (governed, not random). | [comsol_validation_package.md](comsol_validation_package.md), [comsol/](comsol/), `compare_comsol.py` |

**Resolved this round:** co-authors Naman Shreyas Rindani + Ayachi
Padmanabh Mishra (IITD-AD) are in the author block; Lennox → Eblana
Photonics; affiliation 2 → Warwick (department to confirm).

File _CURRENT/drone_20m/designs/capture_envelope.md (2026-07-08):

# Input-drift capture envelopes (the prof's acceptance model, executed)

*(Benoy 2026-07-08: "for an input spot pattern drift or angle drift in the
beam exits the [exit] hole with decent clearance it's good" + "Check this
for each of your designs." Tool: `capture_envelope.py`; data:
[capture_envelope.csv](capture_envelope.csv).)*

## What was measured

Per design and per launch degree of freedom (in-plane offset t, sagittal
offset z, tangential tilt, sagittal tilt), bisection to the largest drift
that still (a) completes the full path with no clipping, (b) keeps every
pre-exit pass clear of the coupling hole, and (c) exits with the whole
beam inside the hole rim (clearance ≥ 0). The capture envelope is the
per-axis box; P_cap = worst position axis, Θ_cap = worst angle axis.

## Results

| design | OPL (m) | P_cap (mm) | Θ_cap (mrad) | vs Al-flexure demand (0.07 mm / 0.20 mrad) | vs hybrid-plastic demand (0.17 mm / 0.55 mrad) |
|---|---|---|---|---|---|
| D190 25.7 m tri-gas | 25.7 | 0.499 | 10.1 | 7.1× / 51× | 2.9× / 18× |
| D160 27 m | 26.7 | 1.055 | 14.2 | 15× / 71× | 6.2× / 26× |
| D180 24 m H2 (2121.8 nm) | 23.8 | 0.411 | 6.0 | 5.9× / 30× | 2.4× / 11× |
| D180 15 m sparse | 15.3 | 1.034 | 18.8 | 15× / 94× | 6.1× / 34× |
| D130 9.1 m half-inch (0.8 mm hole) | 9.1 | 0.507 | 8.0 | 7.2× / 40× | 3.0× / 15× |
| D190 19 m two-inch | 19.0 | 1.137 | 13.2 | 16× / 66× | 6.7× / 24× |
| D190 29 m ceiling | 29.0 | 0.473 | 3.0 | 6.8× / 15× | 2.8× / 5.5× |
| D150 20.7 m flight | 20.7 | 0.410 | 4.2 | 5.9× / 21× | 2.4× / 7.6× |
| D180 22 m | 22.3 | 0.366 | 6.5 | 5.2× / 32× | 2.2× / 12× |

Demand = alignment-residual regime + drone operational-drift vector from
the prof's framework, conservative arithmetic sum: Al isostatic flexure
uses the easy regime (0.02 mm / 0.05 mrad) + drone Al-flexure drift
(0.05 mm / 0.15 mrad); hybrid plastic body + Al mirror cartridge uses the
medium regime (0.05 / 0.15) + hybrid drone drift (0.12 / 0.40).

## Findings

1. **Every menu design passes both architectures**, minimum margins 2.2×
   in position (D180_22m vs hybrid) and 5.5× in angle (29 m ceiling vs
   hybrid). Even the *hard* alignment regime plus hybrid drift
   (0.24 mm / 0.80 mrad summed) is inside every envelope.
2. **Angle capture is the architecture's quiet superpower** — 3–19 mrad,
   1–2 orders above the demand. The re-entrant ring tolerates launch
   angle drift far better than launch position drift because tilt
   deforms the Lissajous pattern slowly while position drift translates
   it toward the hole rim roughly 1:1.
3. **Position capture tracks exit-hole clearance**, as the acceptance
   model predicts: the sparse/2-inch designs (largest hole margins)
   capture >1 mm; the 29 m ceiling design and the walk-tight 22 m sit
   at 0.37–0.47 mm — still 5–7× the flexure demand.
4. The tightest angle budget in the menu is the 29 m ceiling design
   (3.0 mrad) — consistent with its role as the passive-build boundary.
5. Capture ≫ residual+drift for every design means: **construction error
   within the capture box is fully recoverable by one alignment session,
   and post-alignment drone drift never walks the exit out of the hole**
   — the two claims the prof's framework asks a paper to state
   separately.

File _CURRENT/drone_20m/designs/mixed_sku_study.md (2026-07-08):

# Mixed-SKU rings: two alternating catalog ROCs in one cell

*(User-requested exploration, 2026-07-08: "different combinations of
mirrors". Tools: `mixed_sku_explore.py` (analytic unit-cell prescreen +
exact-trace refinement) and `mixed_sku_pass2.py` (separation-aware
re-optimization). Data: [mixed_sku_results.csv](mixed_sku_results.csv),
[mixed_sku_pass2.csv](mixed_sku_pass2.csv).)*

## The idea

Every published chord-skip/toroidal design — and our whole menu — uses
one mirror type for the full ring. With even N and odd skip s the beam
alternates A,B,A,B... between two mirror populations, so a two-SKU ring
is a legal re-entrant system whose transverse phase per two bounces
follows the alternating unit cell

    cos θ₂ = ½ tr[ M(f_B) P(L) M(f_A) P(L) ],   per plane,

giving the architecture a **second closure knob**: (N, s, k)
combinations that no single catalog ROC can close may close for a pair.
(The formula reduces exactly to the uniform cos 2θ₁ for f_A = f_B —
verified against the known drone_20m closure.)

## What the exploration found

27 combos (N ∈ {12, 14, 16} × nine adjacent/wide catalog ROC pairs),
analytic 2 µm R_ring prescreen (the closure valleys are ~5 µm wide —
coarser scans alias at high k), exact Nelder-Mead refinement of launch
and ring at each analytic root:

* **Mixed rings close, exactly.** Dozens of candidates reached exit
  miss = 0.000–0.01 mm with clean hole clearance (0.3–2.5 mm) at
  nominal paths of **30–69 m** — far beyond the uniform architecture's
  38.6 m geometric ceiling in the same ≤Ø190 envelopes.
* **Several of the longest closures are mix-only.** Uniform
  counterfactual (same N, s, k, ±1.5–2 mm R window): the four longest
  (68.9, 68.4, 64.7, 64.6 m) close for *neither* ROC alone.
* **Spot crowding is the binding constraint.** All those k = 19–33
  patterns pack 19–33 spots per 1″ mirror; pass 1 landed at separation
  margins of −0.5…−2.1 mm, and the separation-aware pass 2 (extended to
  the full top-40, 43.7–68.4 m) recovered them to −0.3…−0.7 — except
  exactly one. On 1″ apertures the feasible mixed design is a singular
  point in the closure map, not a family.

## The verified design: 51.7 m in Ø180 with catalog mirrors

| parameter | value |
|---|---|
| ring | N = 12, skip 5, R_ring = 71.928 mm, envelope Ø180 |
| mirrors | alternating **CM254-250-M01 (ROC 500)** / **CM254-375-M01 (ROC 750)**, 6 + 6 |
| pattern | k = 31 spots/mirror, **372 chords**, OPL **51.66 m** |
| throughput | 69.0 % at R = 0.999 (T = R³⁷¹) |
| checks | exit miss 2.3 µm; hole clearance +2.46 mm; worst-pair separation **+0.03 mm**; aperture clear |
| launch | w₀ = 0.333 mm at 0.64 × half-chord; tilts 30.8/40.1 mrad |
| counterfactual | k = 31 closure **does not exist** for uniform ROC 500 nor ROC 750 in the R window — mix-only |

Honest tier placement: the +0.03 mm worst-pair margin is a hair — build
error walks spots by ~0.3–0.5 mm even at flight grade, so this is an
**active-alignment-tier** design (same tier as the uniform 38.6 m
record) and CH₄/NH₃-only (H₂'s +13 % spot growth erases the margin).
Within that tier it is the new architecture record: **51.7 m vs 38.6 m
uniform (+34 %) in the same Ø180 envelope, still all-catalog parts**
(one SKU drilled, two SKUs purchased).

## The endgame: three more experiments and the complete verdict

1. **Margin-aware native search (separation in the objective from the
   start)** found two nominal designs with real separation margins —
   30.5 m/Ø186 (sep +0.33 mm) and 20.8 m/Ø130 — i.e. separation CAN be
   bought at moderate k.
2. **Dedicated mixed Monte-Carlo** (baseline alternating ROC composed
   with random flight-grade errors) then failed them at 17–34 % path
   completion, and the diagnosis is exact: the optimizer bought
   separation by inflating pattern amplitude to the aperture edge —
   +0.25 mm of uniform ROC error or 0.1 mrad of tilt clips the beam by
   bounce ~24. On 1″ apertures, mixed rings can hold separation OR
   aperture headroom, not both.
3. **Two-inch mixed rings** (N = 8 alternating CM508 pairs, both
   margins demanded) removed the aperture constraint — headroom up to
   14.7 mm — and separation STILL stayed negative (−0.3…−1.8 mm across
   23 refined candidates). This isolates the true root cause: the
   mixed analytic prescreen checks *closure only*, whereas the uniform
   search also screens *constellation quality* (near-degenerate phase
   pairs whose worst-pair distance is a vanishing fraction of the
   amplitude, immune to amplitude scaling). Mixed candidates were never
   degeneracy-filtered, so the refiner fights structurally-degenerate
   Lissajous patterns.

**Verdict for the paper:** mixed two-SKU rings verifiably close
patterns no single curvature can (51.7 m demonstrated, counterfactual
checked), but making them *build-robust* requires porting the
constellation-degeneracy screen to the alternating-cell phase structure
— a well-defined piece of number theory (the two-subsequence Lissajous
of the unit-cell eigenbasis) and the single identified blocker. Until
then the mixed family is an active-alignment capability.

## Why the others stay crowded (and what would free them)

At k = 29–33 the pattern density on a 1″ aperture is at the packing
limit: mean nearest-neighbour spacing approaches 2w and the Lissajous
worst pair goes negative. The levers, in order of leverage:

1. **2″ mirrors** — the same mixed closures on CM508 apertures double
   every separation; the 55–69 m closures found here would clear by
   millimetres (consistent with the established "2″ beats the 39 m
   ceiling" note — mixing multiplies that route).
2. **Separation-in-the-loop from the start** — pass 2 bolted separation
   onto converged closures; a mixed-native search with the walk-budget
   objective (as in the uniform v8 harness) would trade a few metres
   for margin the way drone_20m's family did.
3. **Lower-k mixed hunts** — low-k mixed closures are sparse in the
   R-window (that scarcity is itself a finding: mixing shifts θ₂ enough
   that k ≤ 13 roots mostly leave the catalog ring-radius range).

## Take-away for the paper

Mixed-SKU rings are a genuinely new degree of freedom for re-entrant
ring cells: the alternating unit cell closes patterns single-ROC rings
cannot, extending the verified nominal ceiling of the catalog-parts
architecture from 38.6 m to **51.7 m in Ø180**, with a clear,
quantified path (aperture, margin-aware search) to making such designs
build-robust. Even as an active-tier result it strengthens the paper's
central claim: chord-skip + closure-tuning turns a pile of catalog
mirrors into a design space, and that space is larger than one SKU.

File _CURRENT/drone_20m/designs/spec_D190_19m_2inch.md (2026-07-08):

# As-built spec -- class D190: 19.04 m in a 182 mm envelope

8 x Thorlabs **CM508-150-M01** (1" protected-gold concave, ROC 300 mm, CA radius 22.9 mm, R = 0.999 @ 1654 nm)

## 1. Machined ring housing

| item | value |
|---|---|
| mirror-face ring radius R_ring | **67.794 mm** (closure-critical: machine to +/-0.05 mm, then tune by ring temperature / shims) |
| mirrors | N = 8, every 45.00 deg |
| pocket normal | radial, facing cell centre |
| cell height (inner) | 25 mm |
| assembly envelope | 182 mm dia (R_ring + 23 mm substrate+wall) |
| enclosed gas volume | 0.36 L |
| est. mass (mirrors + Al ring) | ~632 g |
| optics cost | 8 x ~$74 = ~$592 |

Mirror placement (cell frame, z = 0 mid-height plane):

| mirror | x [mm] | y [mm] | azimuth [deg] | normal azimuth [deg] |
|---|---|---|---|---|
| M0 |  +67.794 | +0.000 | 0.00 |  180.00 |
| M1 |  +47.937 |  +47.937 | 45.00 |  225.00 |
| M2 | +0.000 |  +67.794 | 90.00 |  270.00 |
| M3 |  -47.937 |  +47.937 |  135.00 |  315.00 |
| M4 |  -67.794 | +0.000 |  180.00 | 0.00 |
| M5 |  -47.937 |  -47.937 |  225.00 | 45.00 |
| M6 | -0.000 |  -67.794 |  270.00 | 90.00 |
| M7 |  +47.937 |  -47.937 |  315.00 |  135.00 |

## 2. Injection / extraction optics (behind mirror M0)

| item | value |
|---|---|
| entrance hole | radius 1.3 mm through M0, centred at (u, v) = (+0.00, +0.36) mm on the mirror face (u = in-plane, v = height) |
| input beam | 1.3 mm collimated (laser collimator), mode-matched down by a small lens |
| beam at the hole | 1/e^2 radius 0.315 mm (passes the 1.3 mm hole with 100.00 % transmission) |
| in-cell waist | 0.224 mm, located 93.9 mm past the hole (mode-matching lens focus; cell eigenmode ride, beam stays 0.38 mm max) |
| launch tilt, in-plane | -60.76 mrad from the M0->M3 chord |
| launch tilt, out-of-plane | +53.71 mrad |
| launch height offset | +0.36 mm |
| exit beam | back through the same hole, 141.5 deg from the injection axis -- place the detector on that line behind M0 |

## 3. Path accounting

| item | value |
|---|---|
| OPL (hole -> hole) | **19.041 m** |
| chords | 152 legs, mean 125.27 mm (min 118.30, max 131.08) |
| reflections | 151 (R^151 = 85.98 %) |
| spots per mirror | 19 |
| AOI | mean 22.61 deg, max 25.60 deg |
| beam radius in cell | 0.24 - 0.38 mm |
| throughput @ R = 0.999 | **85.98 %** = 100.00 % (hole in+out) x 85.98 % (mirrors) |
| throughput, parametric | T(R) = 1.0000 x R^151  (R = 0.984 -> 8.76 %, R = 0.97 -> 1.01 %) |
| stability | m_tan = +0.547, m_sag = +0.615 (|m| <= 1) |

## 4. Physical-check matrix (exact 3-D ray trace)

| check | margin | verdict |
|---|---|---|
| exits through entrance hole | miss 0.000 mm (tol 0.5) | PASS |
| OPL >= 10.0 m | 19.04 m | PASS |
| intermediate spots clear hole | +3.85 mm | PASS |
| beam edge inside clear aperture | +10.34 mm | PASS |
| spot separation (fringe safety) | +0.95 mm beyond touching (min sep 1.62 mm) | PASS |
| per-plane stability | tan +0.547 / sag +0.615 | PASS |
| envelope | 182 <= 190 mm | PASS |
| mirror packing web | 26.49 mm | PASS |

## 5. Spot constellations (mirror-face coordinates, mm)

u = in-plane (tangential), v = height (sagittal); visit order in parentheses. M0 also shows the hole (H).

- **M0** [H = entrance hole at #0]: (+0.00,+0.36)#0  (+9.22,+6.92)#8  (-1.71,+7.39)#16  (-8.64,+0.67)#24  (+2.54,-6.14)#32  (+8.88,-8.04)#40  (-4.92,-2.13)#48  (-7.19,+5.50)#56  (+5.05,+8.09)#64  (+7.43,+3.91)#72  (-7.44,-4.54)#80  (-5.03,-8.13)#88  (+7.20,-4.94)#96  (+4.90,+2.83)#104  (-8.87,+8.19)#112  (-2.53,+5.65)#120  (+8.63,-1.39)#128  (+1.70,-7.69)#136  (-9.22,-6.50)#144  (+0.00,+0.36)#152
- **M1**: (-1.26,+2.88)#3  (+9.03,-4.53)#11  (-0.01,-8.27)#19  (-9.04,-3.90)#27  (+1.27,+3.54)#35  (+9.18,+8.17)#43  (-3.37,+5.22)#51  (-8.02,-2.65)#59  (+3.81,-7.74)#67  (+8.30,-6.54)#75  (-6.30,+1.33)#83  (-6.18,+7.43)#91  (+6.20,+7.10)#99  (+6.28,+0.60)#107  (-8.30,-6.97)#115  (-3.79,-7.50)#123  (+8.02,-1.95)#131  (+3.35,+5.77)#139  (-9.17,+8.01)#147
- **M2**: (-2.53,-5.65)#6  (+8.63,+1.39)#14  (+1.70,+7.69)#22  (-9.22,+6.50)#30  (+0.00,-0.36)#38  (+9.22,-6.92)#46  (-1.71,-7.39)#54  (-8.64,-0.67)#62  (+2.54,+6.14)#70  (+8.88,+8.04)#78  (-4.92,+2.13)#86  (-7.19,-5.50)#94  (+5.05,-8.09)#102  (+7.43,-3.91)#110  (-7.44,+4.54)#118  (-5.03,+8.13)#126  (+7.20,+4.94)#134  (+4.90,-2.83)#142  (-8.87,-8.19)#150
- **M3**: (-8.30,+6.97)#1  (-3.79,+7.50)#9  (+8.02,+1.95)#17  (+3.35,-5.77)#25  (-9.17,-8.01)#33  (-1.26,-2.88)#41  (+9.03,+4.53)#49  (-0.01,+8.27)#57  (-9.04,+3.90)#65  (+1.27,-3.54)#73  (+9.18,-8.17)#81  (-3.37,-5.22)#89  (-8.02,+2.65)#97  (+3.81,+7.74)#105  (+8.30,+6.54)#113  (-6.30,-1.33)#121  (-6.18,-7.43)#129  (+6.20,-7.10)#137  (+6.28,-0.60)#145
- **M4**: (-7.44,-4.54)#4  (-5.03,-8.13)#12  (+7.20,-4.94)#20  (+4.90,+2.83)#28  (-8.87,+8.19)#36  (-2.53,+5.65)#44  (+8.63,-1.39)#52  (+1.70,-7.69)#60  (-9.22,-6.50)#68  (+0.00,+0.36)#76  (+9.22,+6.92)#84  (-1.71,+7.39)#92  (-8.64,+0.67)#100  (+2.54,-6.14)#108  (+8.88,-8.04)#116  (-4.92,-2.13)#124  (-7.19,+5.50)#132  (+5.05,+8.09)#140  (+7.43,+3.91)#148
- **M5**: (-6.30,+1.33)#7  (-6.18,+7.43)#15  (+6.20,+7.10)#23  (+6.28,+0.60)#31  (-8.30,-6.97)#39  (-3.79,-7.50)#47  (+8.02,-1.95)#55  (+3.35,+5.77)#63  (-9.17,+8.01)#71  (-1.26,+2.88)#79  (+9.03,-4.53)#87  (-0.01,-8.27)#95  (-9.04,-3.90)#103  (+1.27,+3.54)#111  (+9.18,+8.17)#119  (-3.37,+5.22)#127  (-8.02,-2.65)#135  (+3.81,-7.74)#143  (+8.30,-6.54)#151
- **M6**: (+8.88,+8.04)#2  (-4.92,+2.13)#10  (-7.19,-5.50)#18  (+5.05,-8.09)#26  (+7.43,-3.91)#34  (-7.44,+4.54)#42  (-5.03,+8.13)#50  (+7.20,+4.94)#58  (+4.90,-2.83)#66  (-8.87,-8.19)#74  (-2.53,-5.65)#82  (+8.63,+1.39)#90  (+1.70,+7.69)#98  (-9.22,+6.50)#106  (+0.00,-0.36)#114  (+9.22,-6.92)#122  (-1.71,-7.39)#130  (-8.64,-0.67)#138  (+2.54,+6.14)#146
- **M7**: (+9.18,-8.17)#5  (-3.37,-5.22)#13  (-8.02,+2.65)#21  (+3.81,+7.74)#29  (+8.30,+6.54)#37  (-6.30,-1.33)#45  (-6.18,-7.43)#53  (+6.20,-7.10)#61  (+6.28,-0.60)#69  (-8.30,+6.97)#77  (-3.79,+7.50)#85  (+8.02,+1.95)#93  (+3.35,-5.77)#101  (-9.17,-8.01)#109  (-1.26,-2.88)#117  (+9.03,+4.53)#125  (-0.01,+8.27)#133  (-9.04,+3.90)#141  (+1.27,-3.54)#149

Generated by drone_20m/spec_asbuilt.py from the exact ray-traced design; tolerances from the Monte-Carlo study in the same folder.

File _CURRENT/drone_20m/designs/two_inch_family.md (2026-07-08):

# Two-inch family — 8 mirrors, 19 m, and the printability boundary

*(Continuation named in the paper's Discussion, executed 2026-07-08.
Search: `TMPC_FAMILY=two_inch`, N ∈ {7, 8} — the only counts that pack
Ø50.8 mm mirrors under the Ø190 envelope; CM508-series protected gold,
22.9 mm clear-aperture radius. SKU availability to be confirmed at
order time.)*

## The verified designs (flight-grade Monte-Carlo, as-built)

| design | mirrors | chords (k) | OPL | T @0.999 | envelope | MC (flight) |
|---|---|---|---|---|---|---|
| **two-inch long** | 8 × CM508-150 (ROC 300) | 152 (19) | **19.04 m** | **86.0 %** | Ø182 | robust: 100 % completion, sep p05 1.02 mm, hole clear 3.36 mm, walk 0.47 mm |
| **two-inch high-T** | 7 × CM508-500 (ROC 1000) | 105 (15) | 11.61 m | **90.1 %** | Ø187 | robust: 100 %, sep p05 1.03, hole clear 5.39 |
| (nominal only) | 8 × CM508-075 | 184 (23) | 23.76 m | 83.3 % | Ø186 | 97 % completion; separation fails — active tier |

Why they matter: the 19.0 m design delivers drone_20m-class path and
throughput with **half the mirror count (8 pockets to machine, ~US$1.1k
of larger-format optics)** and giant clearances (hole margin 3.8 mm,
aperture margin 10.3 mm nominal) — the simplest long cell in the whole
project.

## The construction-tolerance result (the professor's $200 question, part 2)

Process-mapped Monte-Carlo (same grades as the 1″ study):

| process | 19.0 m completion | verdict |
|---|---|---|
| CNC precision | 100 % | **survives as-built** |
| CNC standard | 100 % | completes; needs the one-time trim |
| printed + machined seats | 100 % | completes; needs trim |
| SLA | 100 % | completes; needs trim |
| MJF/SLS | 100 % | completes; needs trim |
| **FDM (PLA)** | **100 %** | completes; needs trim + fringe caution |

**This is the first design in the project — and, to our knowledge, far
beyond anything published — whose full 152-chord path completes in
every trial at every manufacturing grade including desktop FDM.** The
doubled aperture converts directly into completion robustness. The
honest limits: at the printed grades the *spot bookkeeping* still fails
(pairs wander into each other in a fraction of trials, and the exit
needs the standard ring-trim/launch alignment), so a printed build is
"19 m that reliably folds, one alignment session required, fringe floor
to be verified" — not a fringe-guaranteed as-built instrument. For
scale, the published printed-multipass record is 4.2 m [Anal. Chem.
2020]. A printed 19 m ring at ~$50 of plastic plus $1.1k of mirrors is
a compelling demonstrator and teaching instrument; the drone instrument
remains CNC aluminium.

## Boundary note (recorded for the paper's Discussion)

Under the strict Ø190 cap, 2″ mirrors pack only at N = 7–8, so beating
the 1″ 29.0 m robust ceiling would need k ≥ 21 patterns at pattern
amplitudes where the paraxial prescreen no longer locates the closure
valleys (the max-OPL 2″ hunt refined 27 such candidates; all missed by
1.4–8 mm). "Larger apertures beat the ceiling" therefore holds for
relaxed envelopes (bench cells), while inside the drone envelope the 2″
family's wins are simplicity (7–8 pockets), throughput at length
(86–90 %), and build-grade completion robustness.

## Tri-gas verdict

Both flight-robust designs re-qualify **robust as-built at 1512.2 nm
and at 2121.8 nm** (√λ-scaled Monte-Carlo; the 3.3–5.4 mm hole
clearances absorb the +13 % H₂ spot growth trivially) — the 19.04 m /
8-mirror cell is therefore a full tri-gas member, and on a
parts-count/assembly basis the most practical one in the project.

Files: [robust_menu_twoinch_flight.csv](robust_menu_twoinch_flight.csv),
[construction_tolerance_2inch.csv](construction_tolerance_2inch.csv),
[multigas_twoinch_2121.8nm.csv](multigas_twoinch_2121.8nm.csv),
[multigas_twoinch_1512.2nm.csv](multigas_twoinch_1512.2nm.csv);
spec sheet [spec_D190_19m_2inch.md](spec_D190_19m_2inch.md).

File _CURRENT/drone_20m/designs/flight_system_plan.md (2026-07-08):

# Flight system plan — the integrated three-channel airborne sensor

*(Executes the paper's third next step at design level: architecture,
budgets and interfaces for flying CH₄ + NH₃ + H₂ on one cell.)*

## 1. Architecture

One cell serves all three gases (paper §4.4); the channels differ only
in source, detector and window. Two integration levels:

**Level A — per-mission channel (recommended first flight).** One DFB +
matching detector installed per mission; swap per the build-package
step 9 (collimator focus rescale + window if H₂). Zero optical
complexity added; the tri-gas claim is demonstrated across missions.

**Level B — switched tri-gas (single payload).** All three pigtailed
DFBs into a 1×3 PM fibre switch (or a 3→1 PM combiner accepting the
~3 dB tap loss), one reflective OAP collimator (achromatic across
1.5–2.1 µm — the reason it was specced), sapphire -D window resident,
and a two-detector pickoff behind M0: standard InGaAs and extended
InGaAs side by side with a short-focal lens each (the exit spot is
stationary; the two λ-bands split by a longpass dichroic at ~1.9 µm).
Time-multiplex channels at 1–10 s cadence. Note: NH₃ 1512 nm through
the -D sapphire window costs ~5–8 %/surface (out of AR band) — accept,
or flip to Level A for NH₃ campaigns.

## 2. Mass & power budget (Level B)

| subsystem | mass | power |
|---|---|---|
| cell, pocketed Al Ø185, mirrors, window | ~1.15 kg | — |
| dampers + mounting plate | 0.10 kg | — |
| 3× DFB (butterfly) + switch | 0.25 kg | 3–6 W (TECs) |
| drivers + DAQ/SBC (WMS demod on CPU/FPGA) | 0.30 kg | 4–6 W |
| detectors + TIAs | 0.05 kg | <1 W |
| ring heater duty (trim + anti-dew) | — | 2–5 W avg |
| **total** | **≈1.85 kg** | **≈10–17 W** |

Fits a DJI M300/M350-class payload (2.7 kg) with margin; Level A saves
~0.2 kg and ~4 W.

## 3. Mechanical & environmental interfaces

* Cell rigid on its plate; plate on four 40–60 Sh A isolators to the
  airframe (rigid inside, damped outside — the flight-proven
  configuration for this cell class). Keep the collimator boss and
  detector bracket on the *cell* side of the dampers.
* Thermal: ring PI loop holds setpoint ±0.1 K within a ±18 K ambient
  window (flagship); heater doubles as anti-dew. Below −10 °C ambient,
  add 10 mm foam around the ring (raises heater duty margin).
* Gas: flow-through via the two M5 ports with a 10 µm inlet mesh
  (2–10 s exchange pumped), or slotted-lid open-ring for ~25 ms
  in-flight exchange when plume mapping (accepting ambient dust — P8
  monitor active).
* EMI: DFB drivers and switch leads shielded; TIA at the detector.

## 4. Data pipeline

1. WMS at f ≈ 5–10 kHz, 2f demodulation per channel; line fit per 100 ms.
2. H₂ channel fits a Rautian profile (Dicke-narrowed line).
3. Continuous health metrics: fitted lot-R from DC transmission
   (contamination monitor), residual FFT watch at the chord FSR
   (0.034 cm⁻¹) as the fringe alarm, Allan tracker for drift.
4. Outputs: ppb CH₄ / ppb NH₃ / %LEL H₂ at 1–10 Hz + GPS tag.

## 5. Flight test sequence

1. Ground: full experimental_protocol P1–P8 on the integrated payload.
2. Hover test: P6 in situ (vibration-to-signal on the airframe), 10 min.
3. Transect over a controlled release (CH₄ cylinder + flow controller):
   verify plume detection vs release rate; repeat per channel.
4. Endurance: 20 min mission logging Allan behaviour airborne; the
   drift-vs-averaging knee defines the operational integration time.

## 6. Growth path

The active-tier controller (ring heater = slow loop, ±5 mrad launch
piezo = fast loop, quad detector behind the hole; ≈US$400–700) upgrades
the same airframe payload from 25.7 m to 38.6 m (uniform) or 51.7 m
(two-SKU) once the passive system is flight-proven; the 2-inch-mirror
family search (in progress) may raise the passive ceiling itself.

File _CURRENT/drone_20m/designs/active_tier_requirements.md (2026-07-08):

# What "active alignment" actually requires (Tier-3 actuation spec)

The active-alignment tier holds the architecture's showcase numbers —
38.6 m/Ø169, 26.7 m/Ø157, 22.0 m/Ø155 (1″) and 19.3 m/Ø93/37 mL (½″) —
but "needs active alignment" is only a useful statement with numbers
attached. From the 400-trial Monte-Carlo runs (`results_tol_27m`,
`results_tol_24m_h2`) and the tier menus:

## The gap to close

At the flight build (0.1 mrad class) the Tier-3 designs complete their
full path in ≥ 90–100 % of trials — the pattern survives; what fails is
the *passive* spot bookkeeping: pattern walk p95 of 0.8–3.7 mm against
hole clearances of ±0.5 mm and pair separations of 0.03–0.36 mm. The
actuators must therefore recover ~1–3 mm of coherent pattern walk, not
re-create the pattern.

## Sensitivity ordering (drone_27m 400-trial, exit-drift metric)

| error source | contribution at 1σ | note |
|---|---|---|
| mirror ROC (σ 0.5 mm) | ~200 mrad-class dominant term | measure-and-trim at assembly (0.75 mm ring trim per 1 % ROC — linear law) |
| ring radius (σ 30 µm) | ~6.7 | the in-situ fine knob |
| mirror axial decenter | ~1.5 | machining |
| mirror lateral decenter | ~0.8 | machining |
| launch tilt/position | ~0.1–0.2 | the fast knob |

The ordering says: (1) ROC error is absorbed **once**, at assembly, by
machining the ring to the measured-ROC trim table (all designs show the
linear law, 0.52–0.75 mm per 1 %); (2) residual drift in operation is a
*ring-radius-equivalent* effect at the µm scale plus launch pointing.

## The actuator set (all catalog parts)

1. **Ring thermal trim** — gain α·R_ring = 1.2–1.7 µm/K (Al). A ±10 K
   foil-heater loop = ±12–17 µm of ring radius at millikelvin-limited
   resolution ≪ 1 µm: covers the entire post-assembly closure residual
   for every Tier-3 design. Time constant minutes — the slow loop.
2. **Launch tip/tilt piezo** — exit-drift p95 at flight grade is
   3–15 mrad across the menu; a ±5 mrad piezo tip/tilt with sub-50 µrad
   resolution (any catalog piezo mount) closes pointing in real time —
   the fast loop.
3. **Error signal** — the exit beam itself: a quadrant/position detector
   behind the mirror-0 hole reads walk directly; maximize transmitted
   power + center the quad. No in-cell sensor, no extra optical port.

This is a two-loop controller on two catalog actuators — the same
actuator set the standard build already carries as the one-time trim
(heater + adjustable launch); Tier-3 just runs it closed-loop. The cost
delta over a passive cell is the piezo mount and a quad detector
(~$400–700), which buys +50 % path (25.7 → 38.6 m) in a smaller disc, or
the Ø93/37 mL PVR showcase.

*Caveats: the MC treats the drone vibration spectrum only through the
0.1 mrad flight tolerance class; the closed-loop bandwidth needed against
rotor-band (60–700 Hz) excitation of the *launch* path is set by the
damped-mount transmissibility and should come out of the Fusion-360
modal study on the shipped STEP models.*

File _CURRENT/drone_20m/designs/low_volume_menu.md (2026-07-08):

# Low-volume TMPC family — half-inch (CM127) mirrors, Ø90–130 mm

*(Answers the professor's point that "toroidal cells are supposed to be
low volume cells for H2 and methane leak measurements" with a dedicated
design family, 2026-07-08. Search: `search_drone20m.py` with
`TMPC_FAMILY=half_inch`, classes Ø90–130.)*

Half-inch Thorlabs protected-gold concave mirrors (CM127-xxx-M01, ~$50
each, 5.7 mm clear-aperture radius) shrink the ring — and the gas volume
— by roughly 4× against the 1″ family. The full search + 100-trial
Monte-Carlo tiering gives:

## The verified low-volume menu

| design | mirrors | OPL | T @0.999 | envelope | V_min | PVR | tier |
|---|---|---|---|---|---|---|---|
| **mini leak-sniffer** | 14 × CM127-050 (ROC 100) | **9.11 m** | **90.8 %** | Ø129 | 75 mL | 121 m/L | **flight-robust as-built** (with 0.8 mm hole — see below) |
| smallest robust | 16 × CM127-050 | 7.54 m | 54.9 %* | Ø122 | **40 mL** | **190 m/L** | flight-robust as-built (1.3 mm hole) |
| PVR showcase | 14 × CM127-050 | **19.31 m** | 64.7 % | **Ø93** | **37 mL** | **518 m/L** | active alignment (in-situ trim) |
| near-misses | CM127-050 ×16 n=112 (7.95 m Ø98, 89.5 %), ×14 n=98 with 1.3 mm hole (9.11 m) | | | | | | fail 100-trial MC by 1 percentage point of spot-merge trials |

*the 7.54 m row's throughput includes an exit-truncation loss in the
as-searched launch; a mode-matched relaunch recovers most of it — treat
54.9 % as the floor.

## Where this sits against the commercial low-volume cell

| | IRcell-S4 (best commercial small cell) | mini leak-sniffer (ours) | PVR showcase (ours) |
|---|---|---|---|
| OPL | 4.03 m | **9.11 m (2.3×)** | 19.31 m (4.8×) |
| envelope | Ø106 × 32 mm | Ø129 × ~22 mm | **Ø93 × ~22 mm** |
| gas volume | 31 mL | 75 mL | **37 mL** |
| PVR | 130 m/L | 121 m/L | **518 m/L** |
| throughput | not published (~60 % broadband) | **90.8 %** | 64.7 % |
| mirrors | custom diamond-turned monolith | **catalog, ~$50 × 14** | catalog |
| build class | commercial product | flight-grade CNC, as-built | needs in-situ trim |

The honest reading: at *equal build effort* (passive, as-built) we more
than double the commercial small cell's path at matched PVR with
catalog parts; the 4× PVR / 4.8× path corner exists but only with
active alignment (ring-temperature + launch trim) — the same tier that
holds our 38.6 m 1″ record.

## The hole is the half-inch bottleneck (collimator decision for Dr. Benoy)

The project-standard 1.3 mm beam / 1.3 mm hole occupies a third of the
half-inch aperture diameter (exclusion zone ≈ Ø4 mm of 11.4 mm), which
is what killed several otherwise-robust designs (hole-clearance p05
between −0.04 and −0.6 mm). A **0.8 mm beam + 0.8 mm hole** — i.e. a
smaller collimator than the current spec, still trivially available as
a catalog fiber collimator — was re-searched (`TMPC_W0/TMPC_HOLE_R` env
overrides) and **promotes the 9.11 m / Ø129 / 90.8 % design to
flight-robust as-built** (hole clearance p05: −0.04 → +0.52 mm). The
19.3 m Ø93 star does *not* benefit: its limit is spot crowding on the
small aperture, not the hole.

**Decision needed:** approve the smaller collimator for the half-inch
family only (the 1″ menu keeps the 1.3 mm standard; both use the same
fiber-DFB source, different collimation package).

## Gas exchange (the point of low volume on a drone)

| design | V_min | τ @0.5 SLM | @1 SLM | @2 SLM | open-flow transit* |
|---|---|---|---|---|---|
| 9.1 m mini Ø129 | 75 mL | 9.0 s | 4.5 s | 2.3 s | ~26 ms |
| 7.5 m Ø122 | 40 mL | 4.8 s | 2.4 s | 1.2 s | ~25 ms |
| 19.3 m Ø93 showcase | 37 mL | 4.4 s | 2.2 s | 1.1 s | ~19 ms |
| (1″ drone_14cm, for scale) | 200 mL | 24 s | 12 s | 6 s | ~28 ms |

*open ring (lids slotted/mesh, IRcell-S-style flow-through) at 5 m/s
drone airspeed — the cell clears in one body-length of flight, i.e.
plume mapping at the flight-controller rate; the pumped numbers are for
the sealed configuration.

## Physics notes

* Spot sizes do **not** shrink with the mirror: w is set by chord length
  and ROC, so the half aperture crowds patterns ~4× harder — dense
  patterns (k ≥ 11) die at build tolerances that the 1″ family shrugs
  off. The robust half-inch designs are all sparse (k = 5–7).
* Packing floor: Ø93 envelope at N = 14 (found), D90 class returned
  zero feasible — Ø93 is the geometric floor of the catalog half-inch
  chord-skip family with this hole.
* Menus: [robust_menu_halfinch_flight.csv](robust_menu_halfinch_flight.csv),
  [robust_menu_minihole_flight.csv](robust_menu_minihole_flight.csv)
  (+ research-grade variants); raw searches in `results_halfinch*/`.

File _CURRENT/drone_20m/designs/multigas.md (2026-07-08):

# Tri-gas operation: CH₄ 1653.7 nm, NH₃ 1512.2 nm, H₂ 2121.8 nm

*(Dr. Benoy, 2026-07-08: "Also do for hydrogen at 2121.8 nm. At the
opposite end of the spectrum you can do ammonia at 1512.2 nm. These are
the three interesting gases.")*

## 1. Why the same cells work at all three wavelengths

The re-entrance closure, chord geometry, OPL, throughput and spot
*positions* are pure ray geometry — wavelength-independent. The cavity
eigen-q obeys q = (Aq+B)/(Cq+D) whose solution fixes the Rayleigh range
z_R from the ABCD matrix alone, so every Gaussian spot radius scales as
√λ with unchanged waist locations. Re-qualifying a design at a new line
therefore means: scale the launch waist by √(λ/1654 nm) (a collimator
focus-ring turn), re-run the full check matrix, and re-run the build
Monte-Carlo — which is what `multigas_verify.py` does
([multigas_2121.8nm.csv](multigas_2121.8nm.csv),
[multigas_1512.2nm.csv](multigas_1512.2nm.csv)).

* NH₃ 1512.2 nm: spots **shrink** 4.4 % — every margin grows.
* H₂ 2121.8 nm: spots **grow** 13.3 % — separation, hole clearance and
  hole exit all tighten; this is the qualifying case.

## 2. The tri-gas menu (100-trial Monte-Carlo, as-built, no realignment)

<p align="center">
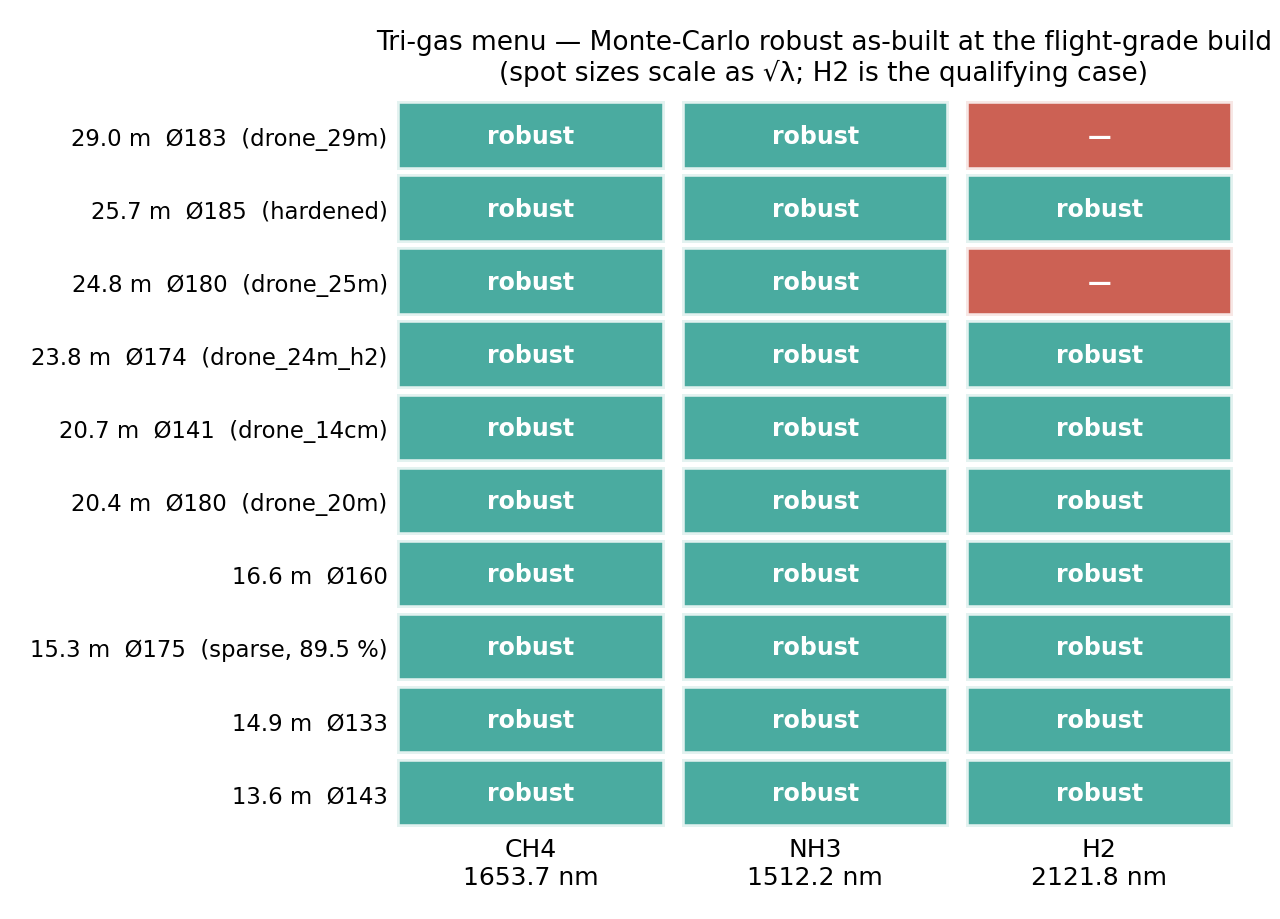
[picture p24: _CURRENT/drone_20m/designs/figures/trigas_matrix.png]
tri-gas robustness matrix
  
</p>

**Flight-grade build (0.1 mrad class — the drone build):**

| design | envelope | OPL | T @0.999 | CH₄ 1654 | NH₃ 1512 | H₂ 2122 |
|---|---|---|---|---|---|---|
| drone_29m | Ø183 | 28.99 m | 76.6 % | ✅ | ✅ | ✖ (sep+exit margin) |
| **25.7 m hardened** (walk-budget 0.8 search) | Ø185 | **25.72 m** | 83.9 % | ✅ | ✅ | **✅ — new tri-gas OPL ceiling** |
| drone_25m | Ø180 | 24.77 m | 83.9 % | ✅ | ✅ | ✖ (sep margin) |
| **H₂-optimised 24m** | **Ø174** | **23.83 m** | 83.9 % | ✅* | ✅* | **✅** |
| drone_20m | Ø180 | 20.38 m | 86.7 % | ✅ (also research-grade) | ✅ | **✅** |
| drone_14cm | **Ø141** | 20.66 m | 81.6 % | ✅ | ✅ | **✅** |
| 16.6 m balanced | Ø160 | 16.60 m | 86.8 % | ✅ | ✅ | **✅** |
| **15.3 m sparse** (7 spots/mirror) | Ø175 | 15.30 m | **89.5 %** | ✅ | ✅ | **✅** |
| 14.9 m small | Ø133 | 14.85 m | 82.8 % | ✅ | ✅ | **✅** |
| 13.6 m max-T | Ø143 | 13.64 m | 87.7 % | ✅ | ✅ | **✅** |

*(The hardened 25.7 m and sparse 15.3 m rows were re-verified at both
gas lines with the same √λ-scaled Monte-Carlo:
[multigas_hardened_2121.8nm.csv](multigas_hardened_2121.8nm.csv),
[multigas_hardened_1512.2nm.csv](multigas_hardened_1512.2nm.csv) —
the walk-budget-0.8 margins absorb the +13.3 % H₂ spot growth, which is
exactly the "tolerance as a search input" mechanism working across
wavelength.)*

<p align="center">
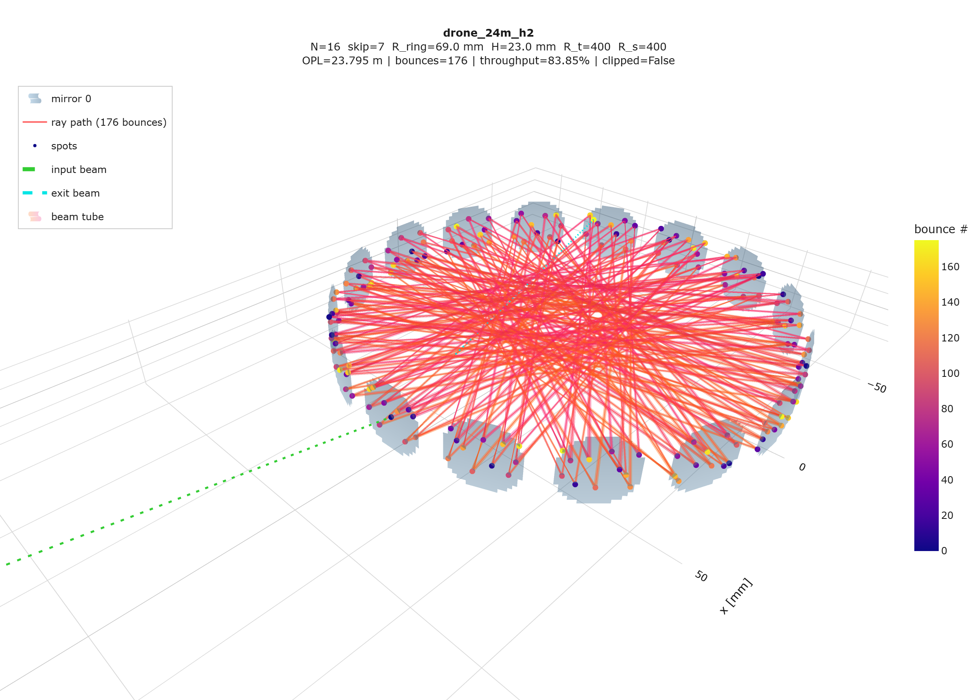
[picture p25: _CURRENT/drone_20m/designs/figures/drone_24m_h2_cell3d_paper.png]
drone_24m_h2: 176-bounce light path at 2121.8 nm
  
</p>

*The traced 176-chord path of the new H₂ design (`drone_24m_h2`),
Optiland-cross-validated at 2121.8 nm to 0.000 µm RMS; 400-trial
flight-grade Monte-Carlo: 176/176 bounces in every trial, zero clipping,
spot-walk p95 = 0.45 mm. Interactive:
[drone_24m_h2_experiment.html](figures/drone_24m_h2_experiment.html).*

*The new 23.83 m design (CM254-200-M01, N=16, skip 7, n=176, R_ring
69.014 mm) came from re-running the full search harness at 2121.8 nm; it
is the same mirror family as drone_25m on a 2.7 mm smaller ring, trading
0.9 m of path for H₂-robust margins (MC at 2122 nm: 100 % completion,
sep p05 = 1.02 mm, hole clearance p05 = 1.75 mm, walk p95 = 0.42 mm).
Feasibility at the shorter wavelengths follows a fortiori (smaller
spots); its 1654/1512 MC rows are in
[robust_menu_h2_flight.csv](robust_menu_h2_flight.csv).*

**Takeaways:** every design in the menu is a tri-gas cell for NH₃+CH₄;
six designs including both 20 m cells qualify for all three gases; the
H₂ ceiling is 23.8 m @ Ø174 instead of 29.0 m @ Ø183 — the √λ spot
growth costs one menu rung at the long-wavelength end. A cell built for
H₂ margins runs the other two gases with margin to spare, so **one
hardware build serves all three gases** (swap laser + detector +
window coating; the gold mirrors cover 0.8–20 µm).

## 3. Line data and what 20 m actually detects

HITRAN2020 values (fetched via HAPI), 296 K, 1 atm air, base-e:

| gas | line | λ | S [cm/molec] | peak absorbance per ppm·m | LOD @ NEA 1e-4, 20.4 m | LOD @ NEA 1e-6 (WMS) |
|---|---|---|---|---|---|---|
| CH₄ | 2ν₃ **R(3) triplet** 6046.94–6046.96 cm⁻¹ | 1653.73 nm | 3.16×10⁻²¹ (sum) | 3.8×10⁻⁵ | **129 ppb** | 1.3 ppb |
| NH₃ | ν₁+ν₃ multiplet at 6612.73 cm⁻¹ | 1512.24 nm | 2.26×10⁻²¹ (5.5×10⁻²¹ blended) | 5.3×10⁻⁵ | **92 ppb** | 0.9 ppb |
| H₂ | (1-0) S(1) electric quadrupole 4712.9046 cm⁻¹ | 2121.83 nm | 3.19×10⁻²⁶ | 1.6–2.9×10⁻⁹ | **0.17–0.31 %v** | 17–31 ppm |

⚠ **Paper correction:** the 1653.73 nm CH₄ feature is the 2ν₃ **R(3)**
triplet; "R(4)" (used in some of our earlier text and much of the
literature) is the *1651.0 nm* line. Fix before the next draft.

Reading the H₂ row correctly (and honestly): the quadrupole line is
~10⁵ weaker than the others — every H₂ TDLAS sensor in the literature
fights this. The best published direct-absorption result is 12 ppmv at
1 s over an 11.4 m cell at NEA ≈ 3×10⁻⁷ (Westberg et al., Opt. Express
33, 11409, 2025); WMS at NEA 2×10⁻⁶ gave 0.1 %v·m (Avetisov et al.,
Sensors 19, 5313, 2019). With 20.4–23.8 m and a 10⁻⁴ fringe-limited
floor the TMPC delivers 0.15–0.3 %v — and since H₂ safety reporting is
in % of the 4 %v LEL, 0.2 %v = 5 % LEL is already an operationally
useful leak alarm; pushing to tens of ppm needs WMS + the fringe floor
at 10⁻⁶, which is exactly what the enforced spot-separation margin and
wedged windows are for. The H₂ line is also sub-Doppler at 1 atm
(Dicke-narrowed to HWHM ≈ 0.013–0.02 cm⁻¹; γ_self = 0.0024 cm⁻¹/atm):
fit with Rautian/Galatry profiles, not Voigt, and beware etalons whose
FSR matches the narrow line — chord-scale OPDs (tens of cm), which the
spot-separation rule suppresses, matter more than window etalons.

## 3b. Why spot separation is *the* H₂ enabler (etalon-FSR audit)

A parasitic etalon formed by scatter bouncing between two mirrors one
chord apart has OPD = 2L, i.e. FSR = 1/(2L):

| design | chord L | chord-etalon FSR | vs H₂ FWHM 0.026–0.04 cm⁻¹ | worst-pair power coupling |
|---|---|---|---|---|
| 25.7 m tri-gas | 146 mm | 0.034 cm⁻¹ | **matches the line** | 1.5×10⁻¹³ |
| 20.4 m (drone_20m) | 142 mm | 0.035 cm⁻¹ | matches | 5.8×10⁻⁶ |
| 20.7 m (drone_14cm) | 101 mm | 0.049 cm⁻¹ | ~line-scale | 1.7×10⁻⁵ |
| 15.3 m sparse | 137 mm | 0.037 cm⁻¹ | matches | 2.8×10⁻¹⁵ |
| 9.1 m mini (½″) | 93 mm | 0.054 cm⁻¹ | ~line-scale | 1.8×10⁻⁸ |

Every chord-skip cell's chord-scale parasites have FSRs **on the H₂
linewidth** (they'd distort the line shape rather than the baseline), so
they cannot be fitted out and must be suppressed at the source — which is
exactly what the enforced spot-separation margin does (10⁻⁶–10⁻¹⁵ power
coupling before multiplying by mirror scatter). Window etalons
(FSR ≈ 1 cm⁻¹) and full-pattern parasites (FSR < 0.001 cm⁻¹) land far
from the line and behave as fittable slow baseline. For CH₄/NH₃
(FWHM 0.12–0.2 cm⁻¹ at 1 atm) the chord FSRs sit *under* the line as
fast fringes that averaging and fitting handle — another reason H₂ is
the qualifying channel. The hardened designs (25.7 m, 15.3 m) were
selected with the largest margins in the menu, which is why they carry
the H₂ robustness.

## 4. Per-gas hardware chain

| item | CH₄ 1653.7 nm | NH₃ 1512.2 nm | H₂ 2121.8 nm |
|---|---|---|---|
| DFB laser | Eblana EP1654-DM (TO-39/butterfly, 3–10 mW); Norcada 1654 | Eblana EP1512-DM (10 mW, butterfly/DX1); Norcada 1512 | Nanoplus 2122 nm (~5 mW, flight-proven in lit.); LD-PD PL-DFB-2122 butterfly (4–7 mW). Eblana/Norcada: custom inquiry only |
| detector | standard InGaAs (0.9–1.7 µm, nA dark) | standard InGaAs | **extended InGaAs** (Thorlabs FD05D Ø0.5 mm, ~1 µA dark, or Hamamatsu G12183 series; µA-class dark → use small area + TEC) |
| window (wedged, AR, Ø1/2″) | WW10530-C (UVFS) or WW30530-D (sapphire) | WW10530-C (UVFS) | WW30530-D (sapphire; UVFS OH band makes IR-grade FS/sapphire the safe choice) |
| mirrors + cell | unchanged protected gold (0.8–20 µm) — same cell for all three | ← | ← |

## 5. Files

* [multigas_2121.8nm.csv](multigas_2121.8nm.csv), [multigas_1512.2nm.csv](multigas_1512.2nm.csv) — re-verification of the 7-design menu (nominal check matrix + MC at both grades per λ)
* [robust_menu_h2_flight.csv](robust_menu_h2_flight.csv), [robust_menu_h2.csv](robust_menu_h2.csv) — H₂-native search results tiered at flight/research grade (source of the 23.83 m design)
* `search_drone20m.py` now takes `TMPC_WAVELENGTH_MM` env override; `multigas_verify.py` automates the re-qualification

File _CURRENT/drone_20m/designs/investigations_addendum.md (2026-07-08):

## Engineering studies: trigas_26m

* ROC-error compensation: linear ring trim +0.750 mm per 1 % ROC error; feasible over -1.0..+1.0 %.
* Thermal window (aluminium ring, launch frozen): -18..+18 K.
* Thermal window (invar ring, launch frozen): -30..+30 K.
* Beam quality: all checks pass to M2 = 1.30.

## Engineering studies: mini_9m

* ROC-error compensation: linear ring trim +0.520 mm per 1 % ROC error; feasible over -1.0..+1.0 %.
* Thermal window (aluminium ring, launch frozen): -30..+30 K.
* Thermal window (invar ring, launch frozen): -30..+30 K.
* Beam quality: all checks pass to M2 = 1.30.

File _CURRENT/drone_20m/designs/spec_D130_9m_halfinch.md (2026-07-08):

# As-built spec -- class D130: 9.11 m in a 129 mm envelope

14 x Thorlabs **CM127-050-M01** (1" protected-gold concave, ROC 100 mm, CA radius 5.7 mm, R = 0.999 @ 1654 nm)

## 1. Machined ring housing

| item | value |
|---|---|
| mirror-face ring radius R_ring | **51.599 mm** (closure-critical: machine to +/-0.05 mm, then tune by ring temperature / shims) |
| mirrors | N = 14, every 25.71 deg |
| pocket normal | radial, facing cell centre |
| cell height (inner) | 13 mm |
| assembly envelope | 129 mm dia (R_ring + 13 mm substrate+wall) |
| enclosed gas volume | 0.11 L |
| est. mass (mirrors + Al ring) | ~616 g |
| optics cost | 14 x ~$74 = ~$1036 |

Mirror placement (cell frame, z = 0 mid-height plane):

| mirror | x [mm] | y [mm] | azimuth [deg] | normal azimuth [deg] |
|---|---|---|---|---|
| M0 |  +51.599 | +0.000 | 0.00 |  180.00 |
| M1 |  +46.489 |  +22.388 | 25.71 |  205.71 |
| M2 |  +32.172 |  +40.342 | 51.43 |  231.43 |
| M3 |  +11.482 |  +50.306 | 77.14 |  257.14 |
| M4 |  -11.482 |  +50.306 |  102.86 |  282.86 |
| M5 |  -32.172 |  +40.342 |  128.57 |  308.57 |
| M6 |  -46.489 |  +22.388 |  154.29 |  334.29 |
| M7 |  -51.599 | +0.000 |  180.00 | 0.00 |
| M8 |  -46.489 |  -22.388 |  205.71 | 25.71 |
| M9 |  -32.172 |  -40.342 |  231.43 | 51.43 |
| M10 |  -11.482 |  -50.306 |  257.14 | 77.14 |
| M11 |  +11.482 |  -50.306 |  282.86 |  102.86 |
| M12 |  +32.172 |  -40.342 |  308.57 |  128.57 |
| M13 |  +46.489 |  -22.388 |  334.29 |  154.29 |

## 2. Injection / extraction optics (behind mirror M0)

| item | value |
|---|---|
| entrance hole | radius 0.8 mm through M0, centred at (u, v) = (+0.02, +2.45) mm on the mirror face (u = in-plane, v = height) |
| input beam | 0.8 mm collimated (laser collimator), mode-matched down by a small lens |
| beam at the hole | 1/e^2 radius 0.260 mm (passes the 0.8 mm hole with 100.00 % transmission) |
| in-cell waist | 0.200 mm, located 63.1 mm past the hole (mode-matching lens focus; cell eigenmode ride, beam stays 0.33 mm max) |
| launch tilt, in-plane | +44.57 mrad from the M0->M5 chord |
| launch tilt, out-of-plane | -9.68 mrad |
| launch height offset | +2.45 mm |
| exit beam | back through the same hole, 123.5 deg from the injection axis -- place the detector on that line behind M0 |

## 3. Path accounting

| item | value |
|---|---|
| OPL (hole -> hole) | **9.112 m** |
| chords | 98 legs, mean 92.98 mm (min 90.13, max 95.60) |
| reflections | 97 (R^97 = 90.75 %) |
| spots per mirror | 7 |
| AOI | mean 25.71 deg, max 28.27 deg |
| beam radius in cell | 0.18 - 0.33 mm |
| throughput @ R = 0.999 | **90.75 %** = 100.00 % (hole in+out) x 90.75 % (mirrors) |
| throughput, parametric | T(R) = 1.0000 x R^97  (R = 0.984 -> 20.92 %, R = 0.97 -> 5.21 %) |
| stability | m_tan = -0.033, m_sag = +0.163 (|m| <= 1) |

## 4. Physical-check matrix (exact 3-D ray trace)

| check | margin | verdict |
|---|---|---|
| exits through entrance hole | miss 0.000 mm (tol 0.5) | PASS |
| OPL >= 8.0 m | 9.11 m | PASS |
| intermediate spots clear hole | +1.07 mm | PASS |
| beam edge inside clear aperture | +0.42 mm | PASS |
| spot separation (fringe safety) | +0.65 mm beyond touching (min sep 1.20 mm) | PASS |
| per-plane stability | tan -0.033 / sag +0.163 | PASS |
| envelope | 129 <= 130 mm | PASS |
| mirror packing web | -2.44 mm | FAIL |

## 5. Spot constellations (mirror-face coordinates, mm)

u = in-plane (tangential), v = height (sagittal); visit order in parentheses. M0 also shows the hole (H).

- **M0** [H = entrance hole at #0]: (+0.02,+2.45)#0  (+1.93,+1.41)#14  (-3.53,-0.76)#28  (+4.44,-2.26)#42  (-4.44,-2.26)#56  (+3.55,-0.76)#70  (-1.96,+1.41)#84  (+0.02,+2.45)#98
- **M1**: (-4.54,-0.78)#3  (+3.90,+1.14)#17  (-2.47,+2.50)#31  (+0.58,+1.97)#45  (+1.40,+0.18)#59  (-3.13,-1.82)#73  (+4.25,-2.52)#87
- **M2**: (+0.86,-1.69)#6  (-2.69,-2.48)#20  (+4.00,-1.67)#34  (-4.55,+0.49)#48  (+4.17,+2.08)#62  (-2.95,+2.40)#76  (+1.15,+1.00)#90
- **M3**: (+4.36,+2.45)#9  (-3.38,+1.10)#23  (+1.72,-0.90)#37  (+0.28,-2.41)#51  (-2.21,-2.11)#65  (+3.71,-0.52)#79  (-4.48,+1.63)#93
- **M4**: (-1.68,-0.57)#12  (+3.35,+1.41)#26  (-4.35,+2.49)#40  (+4.48,+1.88)#54  (-3.73,-0.17)#68  (+2.24,-1.91)#82  (-0.31,-2.50)#96
- **M5**: (+4.55,+0.14)#1  (-4.02,-1.92)#15  (+2.71,-2.47)#29  (-0.89,-1.41)#43  (-1.12,+0.67)#57  (+2.93,+2.27)#71  (-4.16,+2.25)#85
- **M6**: (-0.55,+2.16)#4  (+2.44,+2.41)#18  (-3.88,+0.83)#32  (+4.54,-1.11)#46  (-4.26,-2.48)#60  (+3.15,-2.04)#74  (-1.44,-0.18)#88
- **M7**: (-4.45,-2.08)#7  (+3.55,-0.43)#21  (-1.96,+1.69)#35  (+0.02,+2.47)#49  (+1.93,+1.69)#63  (-3.53,-0.43)#77  (+4.44,-2.08)#91
- **M8**: (+1.40,-0.18)#10  (-3.12,-2.04)#24  (+4.25,-2.48)#38  (-4.54,-1.11)#52  (+3.90,+0.83)#66  (-2.47,+2.41)#80  (+0.58,+2.16)#94
- **M9**: (+4.17,+2.25)#13  (-2.95,+2.27)#27  (+1.15,+0.67)#41  (+0.86,-1.41)#55  (-2.69,-2.47)#69  (+4.00,-1.92)#83  (-4.55,+0.14)#97
- **M10**: (+0.27,-2.50)#2  (-2.21,-1.91)#16  (+3.71,-0.17)#30  (-4.48,+1.88)#44  (+4.36,+2.49)#58  (-3.37,+1.41)#72  (+1.71,-0.57)#86
- **M11**: (+4.48,+1.63)#5  (-3.73,-0.52)#19  (+2.24,-2.11)#33  (-0.31,-2.41)#47  (-1.69,-0.90)#61  (+3.35,+1.10)#75  (-4.35,+2.45)#89
- **M12**: (-1.12,+1.00)#8  (+2.92,+2.40)#22  (-4.16,+2.08)#36  (+4.55,+0.49)#50  (-4.02,-1.67)#64  (+2.72,-2.48)#78  (-0.89,-1.69)#92
- **M13**: (-4.27,-2.52)#11  (+3.15,-1.82)#25  (-1.43,+0.18)#39  (-0.55,+1.97)#53  (+2.44,+2.50)#67  (-3.89,+1.14)#81  (+4.54,-0.78)#95
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

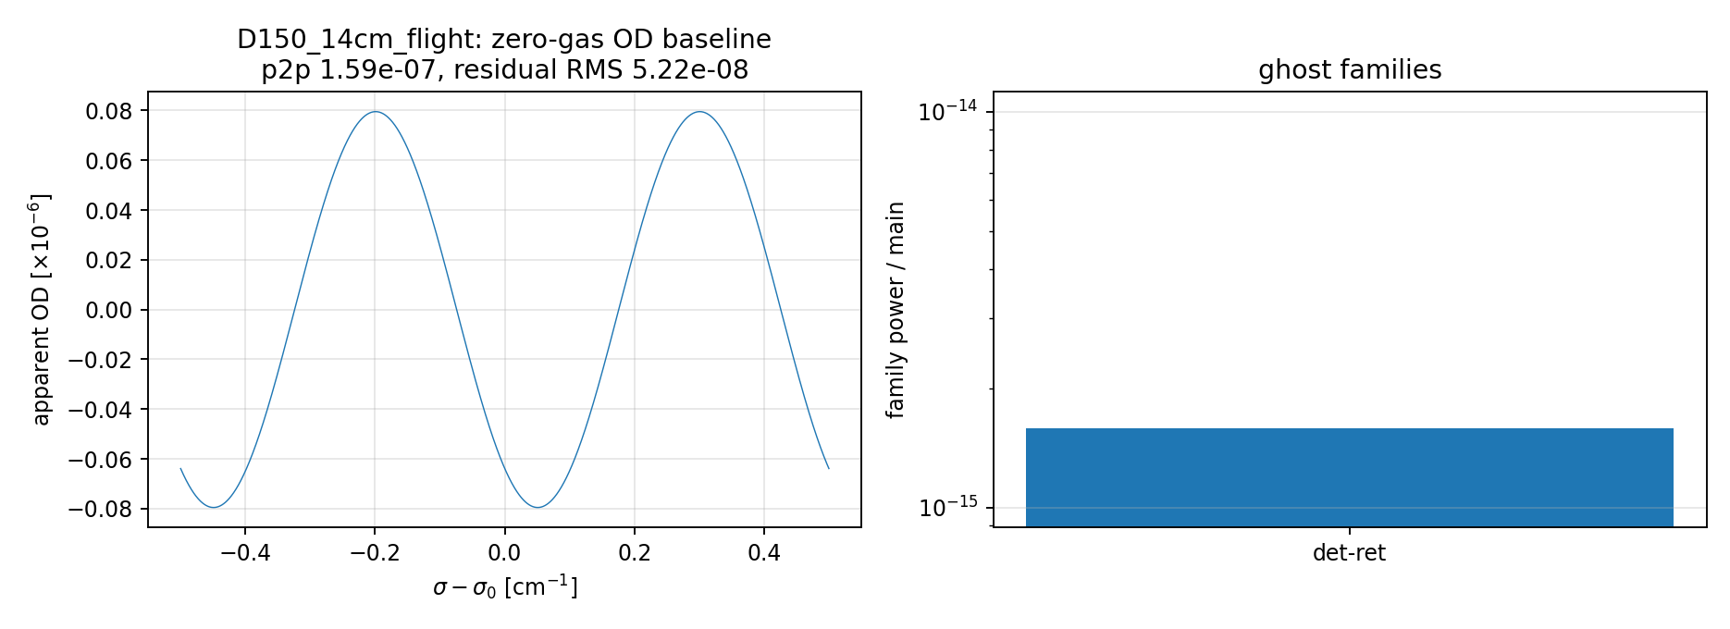
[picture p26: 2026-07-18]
_CURRENT/drone_20m/designs/figures/etalon_od_D150_14cm_flight.png

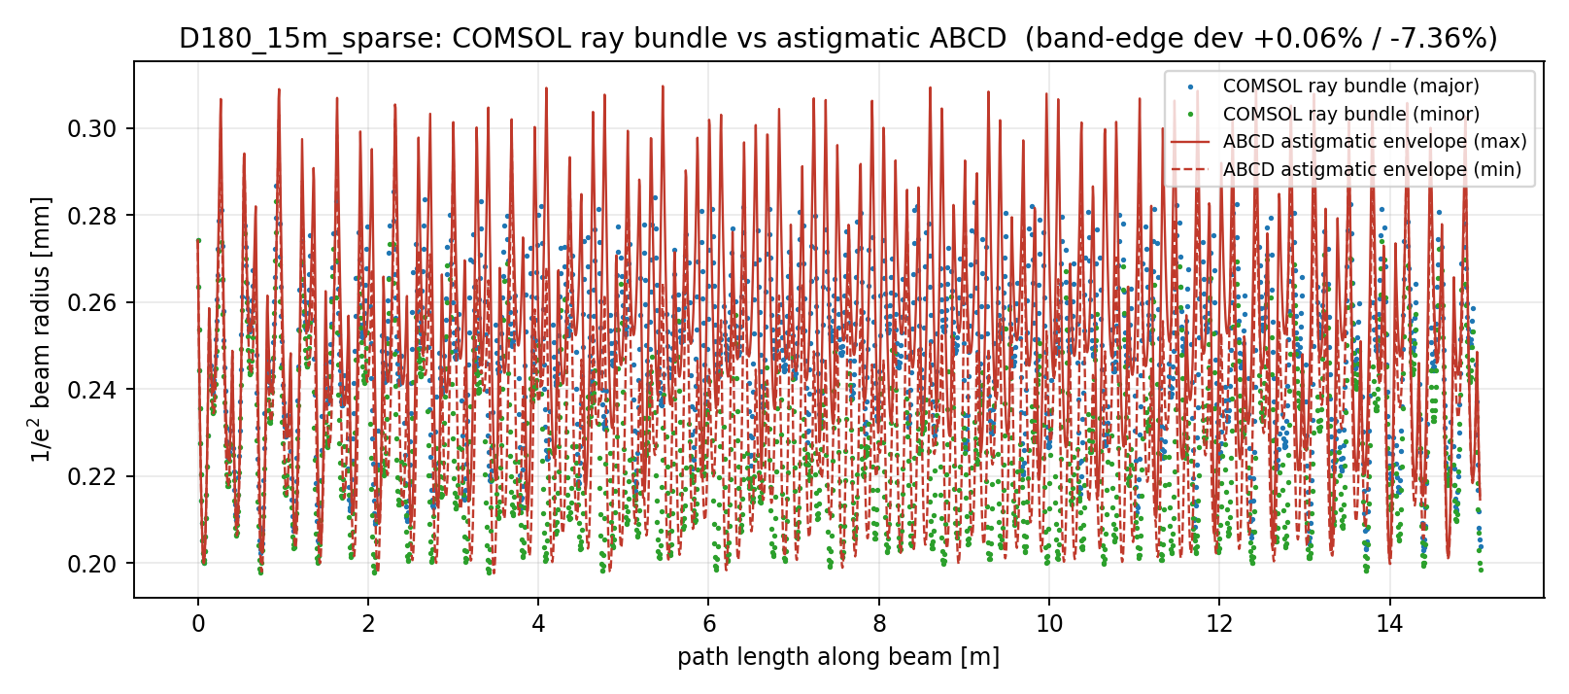
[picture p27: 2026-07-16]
_CURRENT/drone_20m/designs/figures/comsol_beam_D180_15m_sparse.png

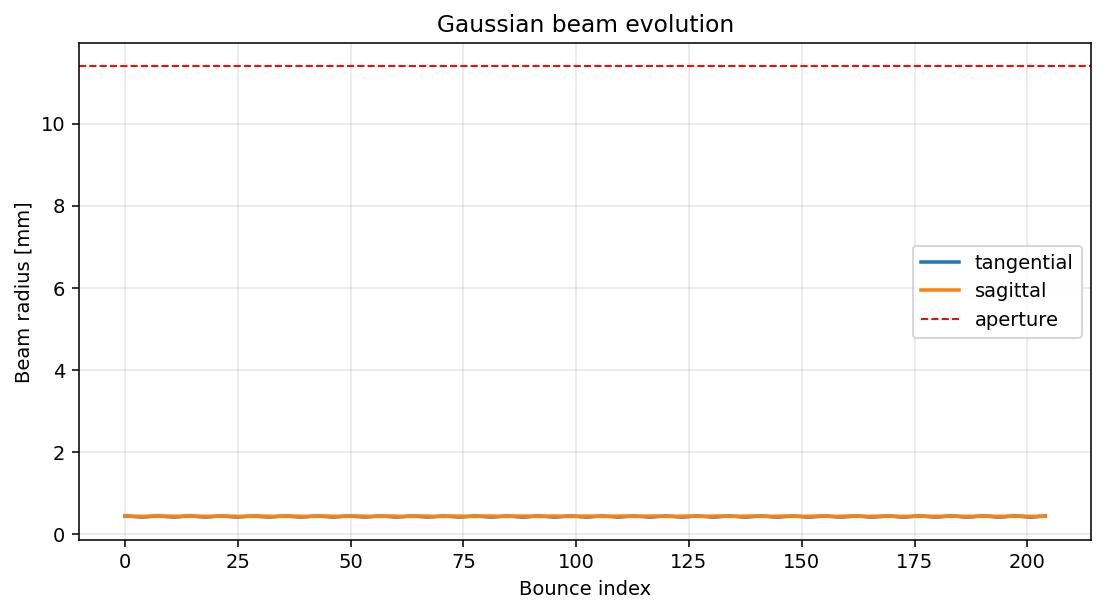
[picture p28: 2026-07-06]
_CURRENT/drone_20m/designs/figures/drone_29m_beam_evolution.png

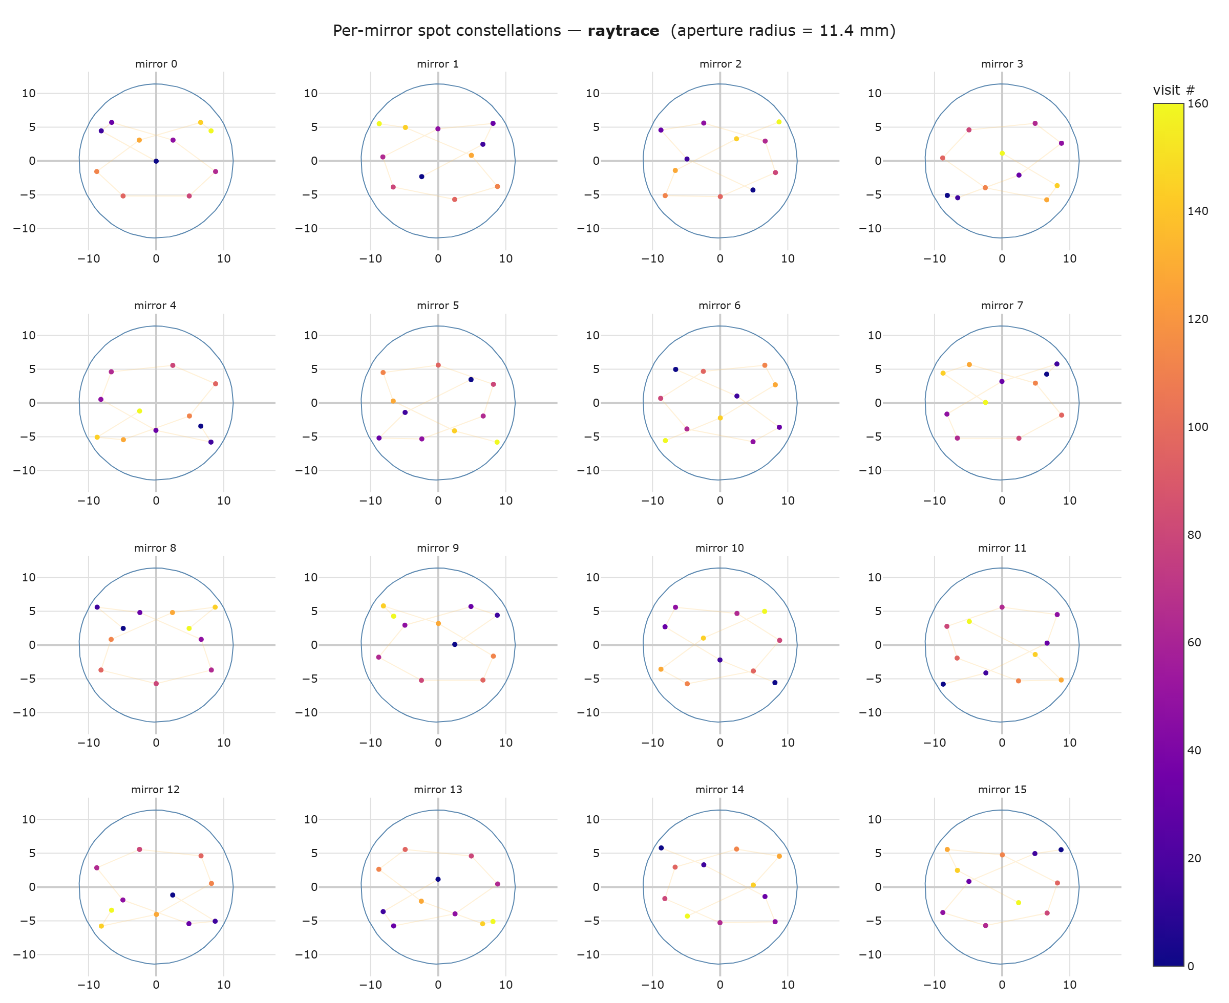
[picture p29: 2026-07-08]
_CURRENT/drone_20m/designs/figures/drone_24m_h2_constellations_paper.png

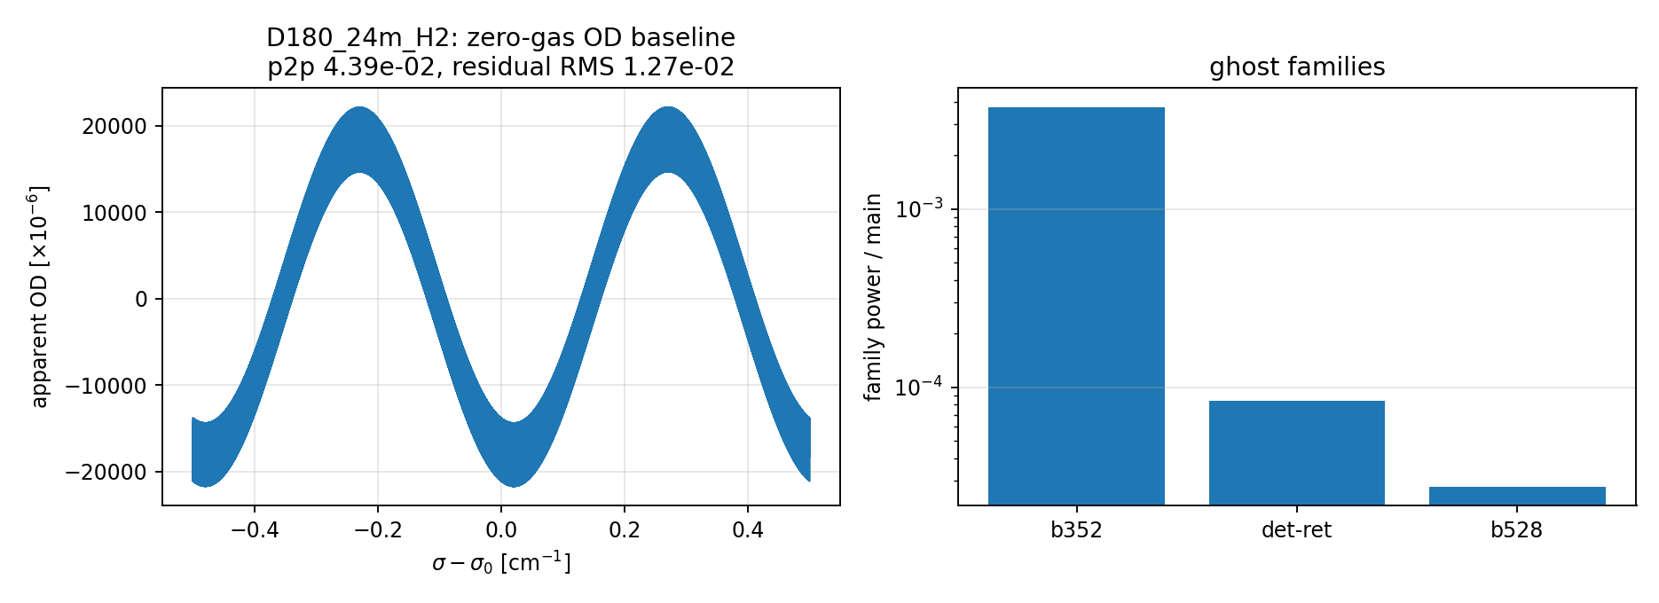
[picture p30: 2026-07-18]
_CURRENT/drone_20m/designs/figures/etalon_od_D180_24m_H2.png

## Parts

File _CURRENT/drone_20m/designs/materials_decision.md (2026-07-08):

# Materials decision (the prof's "choose one combination for drone")

*(Benoy 2026-07-08: "Look up how the various cells are designed using
combination of various materials. Choose one combination for drone. Don't
chose titanium or Invar as they are expensive. Aluminium is a reasonable
choice." + "find a generic low-cost design capable of 3D printing with
plastic/peek." Evidence: [hybrid_materials.csv](hybrid_materials.csv),
[mc5000_drone_yield.csv](mc5000_drone_yield.csv),
[capture_envelope.csv](capture_envelope.csv), CAD in [cad/](cad/).)*

## The decision

**Drone baseline: machined aluminium 6061 monolithic ring** (mirror seats
cut in the body, one CNC setup), O-ring as gas seal only, three-dot epoxy
or spring-clip mirror retention, dowel-pinned collimator, direct 2 mm
detector. No titanium, no Invar: the composed-drift Monte-Carlo shows the
aluminium-flexure drift vector already yields ≥99.9 % on the drone-tier
designs, so the more expensive metals buy margin the designs do not need
(their one thermal weakness — common-mode ring-radius drift — is handled
by the trim law and the ±8–30 K thermal windows, not by CTE exotica).

**Low-cost route: hybrid printed shell + aluminium mirror cartridge.**
The printed polymer shell (with integral base) carries a machined
aluminium annulus holding every mirror pocket and the entry/exit cone on
three dowels — plastic never defines an optical datum. The only machined
part shrinks from the full housing to a simple ring; the print is a
tens-of-dollars part; the cartridge a $100–200 job.

## The evidence chain

1. **Mass** (CAD volumes, real solids): hybrid saves 33–46 % of structure —
   compact Ø141: 817 → 435 g; mini Ø129: 497 → 263 g; max Ø183:
   1270 → 688 g; two-inch Ø182: 1751 → 1056 g (PA12 shell; add ~2–4 %
   for CF-PA12, ~15 % for PEEK).
2. **Stiffness**: 6 mm printed lids hold their first mode at 475–1354 Hz;
   carbon-filled PA12 stays ≥674 Hz on every lid — above the 60–700 Hz
   (dominant <500 Hz) rotor band the aluminium lids clear by an octave.
3. **Drift → yield** (the number that decides): 5000-trial composed
   Monte-Carlo, uniform inside alignment-residual + drone drift:

   | design | Al flexure yield (Wilson LB) | hybrid yield (LB) |
   |---|---|---|
   | tri-gas 25.7 m | **100.00 % (99.92)** | 89.7 % (88.8) |
   | sparse 15.3 m | **100.00 % (99.92)** | 90.4 % (89.6) |
   | two-inch 19.0 m | **100.00 % (99.92)** | **95.0 % (94.3)** |
   | H2-opt. 23.8 m | 99.60 % | 64.6 % |
   | mini 9.1 m (½″) | 99.72 % | 64.8 % |
   | compact 20.7 m | 99.28 % | 63.6 % |
   | 27 m / 29 m / 22.3 m | 98.7 / 95.9 / 92.5 % | 70 / 37 / 53 % |

   Aluminium meets the >99.9 % drone product criterion outright on three
   designs; the hybrid is a research-grade option whose natural carrier is
   the sparse two-inch design (95 %) — exactly the prof's predicted
   trade ("plastic needs a relaxed spot-pattern tolerance envelope").
4. **Capture**: every design's input-drift capture envelope exceeds even
   the hybrid demand box by ≥2.2× position / ≥5.5× angle, so construction
   error is alignable in both architectures; the yield gap above is pure
   operational drift.

## What "generic low-cost 3D-printable design" means concretely

The **two-inch sparse design (19.0 m, Ø182, N = 8, k = 19)** in the hybrid
build: the largest clearances in the menu (hole margin 3.8 mm, aperture
margin 10.3 mm), 100 % as-built completion at every process grade
including FDM, 95 % hybrid drone yield, 1.06 kg structure. Files:
`cad/tmpc_19m_2in_hybrid.step` (+ per-part STLs for print quoting).
A PEEK shell is supported by the same cartridge (PEEK CTE 45–50 ppm/K vs
PA12 100+) for hot environments; for ordinary drone use CF-PA12 is the
better-stiffness cheaper print.

## Rejected options (and why, per the framework)

* **Titanium / Invar** — excluded by cost per the prof's directive; the
  yield table shows aluminium suffices for the drone tier.
* **All-plastic optical datum** (printed pockets carrying mirrors) —
  research-grade construction MC already passes on sparse designs, but the
  drone drift vector (0.7 mm / 3 mrad class) collapses yield; plastic
  creep/CTE/moisture also shrink the thermal closure window to ±2–6 K.
  Lab prototyping only.
* **Bosch-rail frames, O-ring-referenced mirrors, external kinematic
  stacks on the airframe** — the framework's own not-recommended list;
  our architecture never used them (monolithic ring = the anti-Bosch).

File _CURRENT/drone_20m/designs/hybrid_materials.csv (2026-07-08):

design | architecture | shell_material | structure_g | total_g | lid_f1_hz | lid_t_mm
14cm | all-aluminium | Al 6061 (CNC) | 817 | 1137 | 2026 | 4.0
14cm | hybrid plastic + Al cartridge | PA12 (MJF/SLS) | 435 | 755 | 803 | 6.0
14cm | hybrid plastic + Al cartridge | PA12-CF (MJF) | 446 | 766 | 1139 | 6.0
14cm | hybrid plastic + Al cartridge | PLA (FDM) | 484 | 804 | 1011 | 6.0
14cm | hybrid plastic + Al cartridge | Tough resin (SLA) | 472 | 792 | 927 | 6.0
14cm | hybrid plastic + Al cartridge | PEEK (CNC/printed) | 500 | 820 | 997 | 6.0
29m | all-aluminium | Al 6061 (CNC) | 1270 | 1590 | 1199 | 4.0
29m | hybrid plastic + Al cartridge | PA12 (MJF/SLS) | 688 | 1008 | 475 | 6.0
29m | hybrid plastic + Al cartridge | PA12-CF (MJF) | 705 | 1025 | 674 | 6.0
29m | hybrid plastic + Al cartridge | PLA (FDM) | 764 | 1084 | 598 | 6.0
29m | hybrid plastic + Al cartridge | Tough resin (SLA) | 744 | 1064 | 548 | 6.0
29m | hybrid plastic + Al cartridge | PEEK (CNC/printed) | 788 | 1108 | 590 | 6.0
9m_mini | all-aluminium | Al 6061 (CNC) | 497 | 661 | 2409 | 4.0
9m_mini | hybrid plastic + Al cartridge | PA12 (MJF/SLS) | 263 | 427 | 955 | 6.0
9m_mini | hybrid plastic + Al cartridge | PA12-CF (MJF) | 270 | 434 | 1354 | 6.0
9m_mini | hybrid plastic + Al cartridge | PLA (FDM) | 293 | 457 | 1202 | 6.0
9m_mini | hybrid plastic + Al cartridge | Tough resin (SLA) | 285 | 449 | 1102 | 6.0
9m_mini | hybrid plastic + Al cartridge | PEEK (CNC/printed) | 302 | 466 | 1186 | 6.0
19m_2in | all-aluminium | Al 6061 (CNC) | 1751 | 2287 | 1219 | 4.0
19m_2in | hybrid plastic + Al cartridge | PA12 (MJF/SLS) | 1056 | 1592 | 483 | 6.0
19m_2in | hybrid plastic + Al cartridge | PA12-CF (MJF) | 1076 | 1612 | 685 | 6.0
19m_2in | hybrid plastic + Al cartridge | PLA (FDM) | 1145 | 1681 | 608 | 6.0
19m_2in | hybrid plastic + Al cartridge | Tough resin (SLA) | 1122 | 1658 | 558 | 6.0
19m_2in | hybrid plastic + Al cartridge | PEEK (CNC/printed) | 1172 | 1708 | 600 | 6.0

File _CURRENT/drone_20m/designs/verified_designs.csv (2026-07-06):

input_angle_sag | w0_waist | waist_frac | family | sku | roc | N | chord_skip | R_ring | n_target | mode_s | input_offset_z | input_angle | M2 | size_class | envelope_max | opl_min | feasible | reason | opl_m | n_exit | throughput | exit_miss_mm | hole_margin_mm | ap_margin_mm | sep_margin_mm | min_sep_mm | w_max_mm | w_hole_mm | H_req_mm | stab_tan | stab_sag | aoi_deg | early_exit | polished | envelope_mm
0.08498416200177572 | 0.2 | 1.5 | one_inch | CM254-100-M01 | 200.0 | 9 | 4 | 39.894069754527244 | 207 | sin | -0.027327301202361265 | -0.07073452996643326 | 1.1 | D120 | 120.0 | 7.0 | True |  | 16.265223369242086 | 207 | 0.6897687016669682 | 0.07276652030645384 | 2.6679620492926626 | 0.4315001499807227 | 0.3863754730508374 | 0.8343436874885749 | 0.2831113986573215 | 0.2531136611989581 | 23.2048732454489 | 0.6004722054146637 | 0.61361448374369 | 10.570192606870913 | 0.0 | True | 115.78813950905449
0.0 | 0.21161770120875997 | 1.0 | one_inch | CM254-025-M01 | 50.0 | 9 | 4 | 41.34000000000023 | 99 | cos | 5.627276134861159 | 0.037465654889056156 | 1.1 | D120 | 120.0 | 7.0 | False | never returns to hole | 0.0 | 0 | 0.0 | 1.6988732147607086 | -inf | -inf | -inf | 0.0 | 0.0 | 0.23460860143921006 | 0.0 |  |  |  | 0.0 | False
0.08311717542889888 | 0.20790472334344443 | 1.0 | one_inch | CM254-025-M01 | 50.0 | 9 | 4 | 40.940000000000225 | 153 | sin | 0.0 | 0.056573461829994544 | 1.1 | D120 | 120.0 | 7.0 | False | never returns to hole | 0.0 | 0 | 0.0 | 3.782374956779544 | -inf | -inf | -inf | 0.0 | 0.0 | 0.23162153586922957 | 0.0 |  |  |  | 0.0 | False
0.08767878394464804 | 0.2 | 1.0 | one_inch | CM254-075-M01 | 150.0 | 9 | 4 | 39.960000000000235 | 171 | sin | 0.0 | 0.06323264771877748 | 1.1 | D120 | 120.0 | 7.0 | False | never returns to hole | 0.0 | 0 | 0.0 | 0.7896834911980527 | -inf | -inf | -inf | 0.0 | 0.0 | 0.22523680128692233 | 0.0 |  |  |  | 0.0 | False
0.08498416200177572 | 0.2 | 1.5 | one_inch | CM254-100-M01 | 200.0 | 9 | 4 | 39.894069754527244 | 207 | sin | -0.027327301202361265 | -0.07073452996643326 | 1.1 | D130 | 130.0 | 8.5 | True |  | 16.265223369242086 | 207 | 0.6897687016669682 | 0.07276652030645384 | 2.6679620492926626 | 0.4315001499807227 | 0.3863754730508374 | 0.8343436874885749 | 0.2831113986573215 | 0.2531136611989581 | 23.2048732454489 | 0.6004722054146637 | 0.61361448374369 | 10.570192606870913 | 0.0 | True | 115.78813950905449
0.032583678051154405 | 0.36354212160133104 | 1.0 | one_inch | CM254-250-M01 | 500.0 | 11 | 3 | 46.90000000000031 | 121 | sin | 0.0 | 0.04218820252477312 | 1.1 | D130 | 130.0 | 8.5 | False | spots overlap | 8.577706041428327 | 121 | 0.5763322018584007 | 0.17043961092566912 | 1.041913059660399 | 3.393311559463873 | -0.5198664690427659 | 0.008662506391985552 | 0.38686613258125485 | 0.367148156860969 | 14.241334767839168 | 0.8126064405441368 | 0.8926475187016153 | 40.91797519529347 | 0.0 | False | 129.80000000000064
0.0 | 0.2 | 1.0 | one_inch | CM254-025-M01 | 50.0 | 9 | 2 | 42.84000000000026 | 207 | cos | 5.613199610900616 | -0.05075110212345837 | 1.1 | D130 | 130.0 | 8.5 | False | exit miss > 0.35 mm; intermediate spot leaks into hole; spots overlap | 11.400114787534992 | 207 | 0.0030635569489915527 | 0.35539764383102745 | -0.2316969259454864 | 1.9250041834474256 | -2.446936710445617 | 0.30863557045156287 | 2.7920965102827893 | 0.21273144316125184 | 23.105876237794476 | -0.712958198873727 | 0.29243984023292924 | 50.02652938077982 | 0.0 | False | 121.68000000000052
0.1030873412139388 | 0.2 | 1.0 | one_inch | CM254-050-M01 | 100.0 | 10 | 3 | 45.620000000000296 | 250 | sin | 0.0 | 0.08014780116775316 | 1.1 | D130 | 130.0 | 8.5 | False | exit miss > 0.35 mm; spots overlap | 18.45337965716576 | 250 | 0.00018990531777184611 | 0.45350170354615843 | 2.017743826058652 | 1.9074598262177425 | -0.08526013056750031 | 0.4335301112860676 | 0.7325046307630037 | 0.22234936944435957 | 19.241472253961724 | 0.08786057248001578 | 0.4030053182864388 | 36.068791529918265 | 0.0 | False | 127.24000000000059
0.0 | 0.2 | 1.0 | one_inch | CM254-025-M01 | 50.0 | 9 | 2 | 45.38000000000029 | 153 | cos | 6.590839476857414 | -0.048281968305679906 | 1.1 | D130 | 130.0 | 8.5 | False | exit miss > 0.35 mm; intermediate spot leaks into hole; spots overlap | 8.925828243722211 | 153 | 5.8127614560058355e-05 | 0.46938275578591904 | -0.018456353682172466 | 0.6113452978893559 | -1.4062474143590888 | 0.050885015606608255 | 2.6216007163268995 | 0.21423408068148478 | 24.566659375405973 | -0.8112796960767852 | 0.24944723848565553 | 50.03884856399369 | 0.0 | False | 126.76000000000057
0.0 | 0.2 | 1.0 | one_inch | CM254-075-M01 | 150.0 | 10 | 3 | 44.960000000000285 | 130 | cos | 4.494906562559149 | 0.04041402647531925 | 1.1 | D130 | 130.0 | 8.5 | False | never returns to hole | 0.0 | 0 | 0.0 | 0.70515246597117 | -inf | -inf | -inf | 0.0 | 0.0 | 0.22173880204888283 | 0.0 |  |  |  | 0.0 | False
0.02493990905569334 | 0.272975490565492 | 1.0 | one_inch | CM254-025-M01 | 50.0 | 9 | 4 | 46.0200000000003 | 99 | sin | 0.0 | -0.031174468938390505 | 1.1 | D130 | 130.0 | 8.5 | False | never returns to hole | 0.0 | 0 | 0.0 | 0.5786183179546327 | -inf | -inf | -inf | 0.0 | 0.0 | 0.2866288347613522 | 0.0 |  |  |  | 0.0 | False
0.04975067681581331 | 0.2 | 1.0 | one_inch | CM254-050-M01 | 100.0 | 9 | 4 | 45.34000000000031 | 117 | sin | 0.0 | 0.07123025183809681 | 1.1 | D130 | 130.0 | 8.5 | False | never returns to hole | 0.0 | 0 | 0.0 | 0.7199667035844991 | -inf | -inf | -inf | 0.0 | 0.0 | 0.23198240820173555 | 0.0 |  |  |  | 0.0 | False
0.059779342467372446 | 0.2 | 1.0 | one_inch | CM254-075-M01 | 150.0 | 10 | 3 | 45.40000000000028 | 130 | sin | 0.0 | 0.09851711456659512 | 1.1 | D130 | 130.0 | 8.5 | False | never returns to hole | 0.0 | 0 | 0.0 | 3.525665183966199 | -inf | -inf | -inf | 0.0 | 0.0 | 0.22214504526342074 | 0.0 |  |  |  | 0.0 | False
0.09025885068415691 | 0.2 | 1.0 | one_inch | CM254-075-M01 | 150.0 | 9 | 2 | 46.40000000000031 | 153 | sin | 0.0 | 0.08907858902395546 | 1.1 | D130 | 130.0 | 8.5 | False | never returns to hole | 0.0 | 0 | 0.0 | 4.320753967625558 | -inf | -inf | -inf | 0.0 | 0.0 | 0.21485874003021788 | 0.0 |  |  |  | 0.0 | False
0.08311717542889888 | 0.20790472334344443 | 1.0 | one_inch | CM254-025-M01 | 50.0 | 9 | 4 | 40.940000000000225 | 153 | sin | 0.0 | 0.056573461829994544 | 1.1 | D130 | 130.0 | 8.5 | False | never returns to hole | 0.0 | 0 | 0.0 | 3.782374956779544 | -inf | -inf | -inf | 0.0 | 0.0 | 0.23162153586922957 | 0.0 |  |  |  | 0.0 | False
0.0 | 0.25967294400095076 | 1.0 | one_inch | CM254-250-M01 | 500.0 | 11 | 3 | 45.40000000000031 | 121 | cos | 6.740615138154991 | 0.05544497928275033 | 1.1 | D130 | 130.0 | 8.5 | False | ray died at bounce 1 (clipped) | 0.0 | 0 | 0.0 | inf | -inf | -inf | -inf | 0.0 | 0.0 | 0.26882962919973535 | 0.0 |  |  |  |  | False
0.053405752291214546 | 0.24317490785429496 | 1.0 | one_inch | CM254-200-M01 | 400.0 | 10 | 3 | 42.680000000000256 | 170 | sin | 0.0 | 0.0646877752448227 | 1.1 | D130 | 130.0 | 8.5 | False | never returns to hole | 0.0 | 0 | 0.0 | 1.9245276860729112 | -inf | -inf | -inf | 0.0 | 0.0 | 0.2544063074555426 | 0.0 |  |  |  | 0.0 | False
0.08767878394464804 | 0.2 | 1.0 | one_inch | CM254-075-M01 | 150.0 | 9 | 4 | 39.960000000000235 | 171 | sin | 0.0 | 0.06323264771877748 | 1.1 | D130 | 130.0 | 8.5 | False | never returns to hole | 0.0 | 0 | 0.0 | 0.7896834911980527 | -inf | -inf | -inf | 0.0 | 0.0 | 0.22523680128692233 | 0.0 |  |  |  | 0.0 | False
0.05755117683981138 | 0.20731516299816724 | 1.0 | one_inch | CM254-100-M01 | 200.0 | 9 | 4 | 42.88000000000026 | 189 | sin | 0.0 | 0.08314267566330481 | 1.1 | D130 | 130.0 | 8.5 | False | never returns to hole | 0.0 | 0 | 0.0 | 1.5735809684268935 | -inf | -inf | -inf | 0.0 | 0.0 | 0.2334099526836859 | 0.0 |  |  |  | 0.0 | False
0.04672340963154174 | 0.3315759922414288 | 1.0 | one_inch | CM254-150-M01 | 300.0 | 9 | 4 | 45.12000000000029 | 225 | sin | 0.0 | -0.06759733802094811 | 1.1 | D130 | 130.0 | 8.5 | False | never returns to hole | 0.0 | 0 | 0.0 | 2.358628974150186 | -inf | -inf | -inf | 0.0 | 0.0 | 0.33899932020998513 | 0.0 |  |  |  | 0.0 | False
0.05831444223738186 | 0.33248082548783936 | 1.0 | one_inch | CM254-150-M01 | 300.0 | 9 | 4 | 45.700000000000294 | 243 | sin | 0.0 | 0.042181606039920605 | 1.1 | D130 | 130.0 | 8.5 | False | never returns to hole | 0.0 | 0 | 0.0 | 0.7200600881126341 | -inf | -inf | -inf | 0.0 | 0.0 | 0.3400330024243844 | 0.0 |  |  |  | 0.0 | False
0.0 | 0.2 | 1.0 | one_inch | CM254-050-M01 | 100.0 | 10 | 3 | 45.82000000000029 | 250 | cos | 7.829083772380845 | -0.07549918931731038 | 1.1 | D130 | 130.0 | 8.5 | False | never returns to hole | 0.0 | 0 | 0.0 | 5.301271500094658 | -inf | -inf | -inf | 0.0 | 0.0 | 0.22253581190919813 | 0.0 |  |  |  | 0.0 | False
0.044688695198904414 | 0.23529656150960013 | 1.0 | one_inch | CM254-150-M01 | 300.0 | 9 | 4 | 43.700000000000266 | 261 | sin | 0.0 | 0.06465983851588486 | 1.1 | D130 | 130.0 | 8.5 | False | never returns to hole | 0.0 | 0 | 0.0 | 2.0107411563791477 | -inf | -inf | -inf | 0.0 | 0.0 | 0.25423840221333244 | 0.0 |  |  |  | 0.0 | False
0.0 | 0.34496998559720593 | 1.0 | one_inch | CM254-025-M01 | 50.0 | 11 | 4 | 45.40000000000031 | 143 | cos | 8.640382917786651 | -0.04884180248936355 | 1.1 | D130 | 130.0 | 8.5 | False | ray died at bounce 13 (clipped) | 0.0 | 0 | 0.0 | inf | -inf | -inf | -inf | 0.0 | 0.0 | 0.35068031065303573 | 0.0 |  |  |  |  | False
0.0 | 0.2 | 1.0 | one_inch | CM254-025-M01 | 50.0 | 10 | 3 | 42.24000000000026 | 210 | cos | 4.6424618536422315 | -0.06449352403014223 | 1.1 | D130 | 130.0 | 8.5 | False | never returns to hole | 0.0 | 0 | 0.0 | 1.1213955408397538 | -inf | -inf | -inf | 0.0 | 0.0 | 0.21929966907191153 | 0.0 |  |  |  | 0.0 | False
0.10277845000233668 | 0.2 | 1.0 | one_inch | CM254-025-M01 | 50.0 | 9 | 2 | 41.46000000000026 | 207 | sin | 0.0 | -0.07499499405335608 | 1.1 | D130 | 130.0 | 8.5 | False | never returns to hole | 0.0 | 0 | 0.0 | 4.389811522948196 | -inf | -inf | -inf | 0.0 | 0.0 | 0.21194712443476985 | 0.0 |  |  |  | 0.0 | False
0.0 | 0.2 | 1.0 | one_inch | CM254-075-M01 | 150.0 | 10 | 3 | 44.60000000000028 | 290 | cos | 5.3531204582636756 | 0.0973409774868687 | 1.1 | D130 | 130.0 | 8.5 | False | never returns to hole | 0.0 | 0 | 0.0 | 2.513924753665085 | -inf | -inf | -inf | 0.0 | 0.0 | 0.22140881664627213 | 0.0 |  |  |  | 0.0 | False
0.0021590199125305553 | 0.3556803966047528 | 0.8694167346369366 | one_inch | CM254-050-M01 | 100.0 | 12 | 5 | 51.738836958348884 | 180 | cos | 5.103810146973663 | -0.05003553680798464 | 1.1 | D140 | 140.0 | 10.0 | True |  | 17.991308177996718 | 180 | 0.836031021337261 | 5.996632589497809e-08 | 0.37900027260355706 | 5.61458949281387 | 0.8501367152100778 | 2.0133295829332214 | 0.627443552259355 | 0.36144847387467754 | 17.44836785831583 | -0.03535812584697817 | 0.035376671213470656 | 15.145475989449144 | 0.0 | True | 139.47767391669777
0.006069866231166779 | 0.2447833706045881 | 1.04346715894206 | one_inch | CM254-150-M01 | 300.0 | 10 | 3 | 48.314403445108184 | 190 | cos | 3.434904426436362 | 0.05056741148416627 | 1.1 | D140 | 140.0 | 10.0 | True |  | 14.853138274979061 | 190 | 0.8277082323637714 | 8.42359005181579e-07 | 1.7287098173797686 | 2.1433183108994847 | 0.38130102514304864 | 0.9325745203383313 | 0.2975998415334648 | 0.2600275756813347 | 18.84233534778139 | 0.6785969844776647 | 0.788799118678612 | 36.02741771049161 | 0.0 | True | 132.62880689021637
0.0644558419848167 | 0.2 | 0.7336371885307076 | one_inch | CM254-050-M01 | 100.0 | 12 | 5 | 51.3842663050298 | 228 | sin | 0.1902039567642254 | 0.0664352937963364 | 1.1 | D140 | 140.0 | 10.0 | True |  | 22.632801654704128 | 228 | 0.7968302735484668 | 9.665812177607633e-06 | 1.9526512627014938 | 2.0211345580972147 | 0.35084856894179817 | 0.9731614985408064 | 0.445113541038022 | 0.22178371839410663 | 19.262537272775965 | -0.028190645948670046 | 0.04133646014064962 | 15.172275618740034 | 0.0 | True | 138.7685326100596
0.08498416200177572 | 0.2 | 1.5 | one_inch | CM254-100-M01 | 200.0 | 9 | 4 | 39.894069754527244 | 207 | sin | -0.027327301202361265 | -0.07073452996643326 | 1.1 | D140 | 140.0 | 10.0 | True |  | 16.265223369242086 | 207 | 0.6897687016669682 | 0.07276652030645384 | 2.6679620492926626 | 0.4315001499807227 | 0.3863754730508374 | 0.8343436874885749 | 0.2831113986573215 | 0.2531136611989581 | 23.2048732454489 | 0.6004722054146637 | 0.61361448374369 | 10.570192606870913 | 0.0 | True | 115.78813950905449
0.017477208059889338 | 0.29140143705735233 | 1.5 | one_inch | CM254-200-M01 | 400.0 | 10 | 3 | 50.14460600298201 | 130 | sin | -0.13418629694828704 | -0.07207084319066093 | 1.1 | D140 | 140.0 | 10.0 | True |  | 10.547682511598097 | 130 | 0.2242949604529208 | 0.25737010176287617 | 1.7370289957694032 | 0.35351985793644936 | 0.35081225469254784 | 0.9734371855535233 | 0.3601571668565215 | 0.31145181362549534 | 10.717412045346077 | 0.750317968064543 | 0.8348090427879771 | 36.0353671360628 | 0.0 | True | 136.28921200596403
0.033892626502534745 | 0.23036192418837861 | 1.0 | one_inch | CM254-150-M01 | 300.0 | 10 | 3 | 48.280000000000335 | 190 | sin | 0.0 | -0.05795312899355298 | 1.1 | D140 | 140.0 | 10.0 | False | spots overlap | 14.842648066019027 | 190 | 0.09151494405437759 | 0.25923920355846874 | 0.562389161240503 | 2.852465479294038 | -0.11800380209544575 | 0.46097249927600586 | 0.3030842829406609 | 0.24705371898266096 | 13.852087646823252 | 0.6768530394404827 | 0.7900735912444771 | 36.03232781325791 | 0.0 | False | 132.56000000000068
0.04771978701226464 | 0.2 | 1.0 | one_inch | CM254-075-M01 | 150.0 | 9 | 4 | 48.66000000000034 | 153 | sin | 0.0 | -0.04810745034840019 | 1.1 | D140 | 140.0 | 10.0 | False | spots overlap | 14.663707898606926 | 153 | 0.07775049907083649 | 0.2591460275352861 | 1.103710192306614 | 4.12018433549537 | -0.08437480715326989 | 0.4103050259034247 | 0.26506124382368257 | 0.23645978989053915 | 16.38076517803958 | 0.3510464235289773 | 0.3707505877364211 | 10.198827331040565 | 0.0 | False | 133.32000000000068
0.0 | 0.2 | 1.0 | one_inch | CM254-025-M01 | 50.0 | 9 | 2 | 42.84000000000026 | 207 | cos | 5.613199610900616 | -0.05075110212345837 | 1.1 | D140 | 140.0 | 10.0 | False | exit miss > 0.35 mm; intermediate spot leaks into hole; spots overlap | 11.400114787534992 | 207 | 0.0030635569489915527 | 0.35539764383102745 | -0.2316969259454864 | 1.9250041834474256 | -2.446936710445617 | 0.30863557045156287 | 2.7920965102827893 | 0.21273144316125184 | 23.105876237794476 | -0.712958198873727 | 0.29243984023292924 | 50.02652938077982 | 0.0 | False | 121.68000000000052
0.1030873412139388 | 0.2 | 1.0 | one_inch | CM254-050-M01 | 100.0 | 10 | 3 | 45.620000000000296 | 250 | sin | 0.0 | 0.08014780116775316 | 1.1 | D140 | 140.0 | 10.0 | False | exit miss > 0.35 mm; spots overlap | 18.45337965716576 | 250 | 0.00018990531777184611 | 0.45350170354615843 | 2.017743826058652 | 1.9074598262177425 | -0.08526013056750031 | 0.4335301112860676 | 0.7325046307630037 | 0.22234936944435957 | 19.241472253961724 | 0.08786057248001578 | 0.4030053182864388 | 36.068791529918265 | 0.0 | False | 127.24000000000059
0.05506309906124575 | 0.2 | 1.0 | one_inch | CM254-075-M01 | 150.0 | 9 | 4 | 50.16000000000036 | 135 | sin | 0.0 | 0.07927610453420732 | 1.1 | D140 | 140.0 | 10.0 | False | never returns to hole | 0.0 | 0 | 0.0 | 0.6039793917879724 | -inf | -inf | -inf | 0.0 | 0.0 | 0.2385569971024072 | 0.0 |  |  |  | 0.0 | False
0.03240554865128574 | 0.2 | 1.0 | one_inch | CM254-050-M01 | 100.0 | 11 | 5 | 49.68000000000035 | 165 | sin | 0.0 | 0.0463104356290358 | 1.1 | D140 | 140.0 | 10.0 | False | never returns to hole | 0.0 | 0 | 0.0 | 2.578618692945055 | -inf | -inf | -inf | 0.0 | 0.0 | 0.23823662020880199 | 0.0 |  |  |  | 0.0 | False
0.053405752291214546 | 0.24317490785429496 | 1.0 | one_inch | CM254-200-M01 | 400.0 | 10 | 3 | 42.680000000000256 | 170 | sin | 0.0 | 0.0646877752448227 | 1.1 | D140 | 140.0 | 10.0 | False | never returns to hole | 0.0 | 0 | 0.0 | 1.9245276860729112 | -inf | -inf | -inf | 0.0 | 0.0 | 0.2544063074555426 | 0.0 |  |  |  | 0.0 | False
0.03743619524450471 | 0.33910202360157843 | 1.0 | one_inch | CM254-500-M01 | 1000.0 | 12 | 5 | 52.0 | 204 | sin | 0.0 | 0.027632709059217723 | 1.1 | D140 | 140.0 | 10.0 | False | never returns to hole | 0.0 | 0 | 0.0 | 4.72408370517334 | -inf | -inf | -inf | 0.0 | 0.0 | 0.3479534435465292 | 0.0 |  |  |  | 0.0 | False
0.0 | 0.2 | 1.0 | one_inch | CM254-050-M01 | 100.0 | 9 | 4 | 50.30000000000036 | 207 | cos | 5.058548656354404 | -0.07294081885572769 | 1.1 | D140 | 140.0 | 10.0 | False | never returns to hole | 0.0 | 0 | 0.0 | 2.239014835702947 | -inf | -inf | -inf | 0.0 | 0.0 | 0.2387550280316115 | 0.0 |  |  |  | 0.0 | False
0.04672340963154174 | 0.3315759922414288 | 1.0 | one_inch | CM254-150-M01 | 300.0 | 9 | 4 | 45.12000000000029 | 225 | sin | 0.0 | -0.06759733802094811 | 1.1 | D140 | 140.0 | 10.0 | False | never returns to hole | 0.0 | 0 | 0.0 | 2.358628974150186 | -inf | -inf | -inf | 0.0 | 0.0 | 0.33899932020998513 | 0.0 |  |  |  | 0.0 | False
0.0 | 0.2 | 1.0 | one_inch | CM254-050-M01 | 100.0 | 11 | 5 | 50.20000000000036 | 319 | cos | 6.372553211426452 | -0.09160546549303097 | 1.1 | D140 | 140.0 | 10.0 | False | never returns to hole | 0.0 | 0 | 0.0 | 3.424977613432912 | -inf | -inf | -inf | 0.0 | 0.0 | 0.2389755367133693 | 0.0 |  |  |  | 0.0 | False
0.044688695198904414 | 0.23529656150960013 | 1.0 | one_inch | CM254-150-M01 | 300.0 | 9 | 4 | 43.700000000000266 | 261 | sin | 0.0 | 0.06465983851588486 | 1.1 | D140 | 140.0 | 10.0 | False | never returns to hole | 0.0 | 0 | 0.0 | 2.0107411563791477 | -inf | -inf | -inf | 0.0 | 0.0 | 0.25423840221333244 | 0.0 |  |  |  | 0.0 | False
0.04975067681581331 | 0.2 | 1.0 | one_inch | CM254-050-M01 | 100.0 | 9 | 4 | 45.34000000000031 | 117 | sin | 0.0 | 0.07123025183809681 | 1.1 | D140 | 140.0 | 10.0 | False | never returns to hole | 0.0 | 0 | 0.0 | 0.7199667035844991 | -inf | -inf | -inf | 0.0 | 0.0 | 0.23198240820173555 | 0.0 |  |  |  | 0.0 | False
0.05755117683981138 | 0.20731516299816724 | 1.0 | one_inch | CM254-100-M01 | 200.0 | 9 | 4 | 42.88000000000026 | 189 | sin | 0.0 | 0.08314267566330481 | 1.1 | D140 | 140.0 | 10.0 | False | never returns to hole | 0.0 | 0 | 0.0 | 1.5735809684268935 | -inf | -inf | -inf | 0.0 | 0.0 | 0.2334099526836859 | 0.0 |  |  |  | 0.0 | False
0.044455005720541826 | 0.24455332251230827 | 1.0 | one_inch | CM254-200-M01 | 400.0 | 11 | 3 | 46.840000000000316 | 143 | sin | 0.0 | 0.04086286469473691 | 1.1 | D140 | 140.0 | 10.0 | False | never returns to hole | 0.0 | 0 | 0.0 | 4.007444052322028 | -inf | -inf | -inf | 0.0 | 0.0 | 0.25615260153338515 | 0.0 |  |  |  | 0.0 | False
0.08767878394464804 | 0.2 | 1.0 | one_inch | CM254-075-M01 | 150.0 | 9 | 4 | 39.960000000000235 | 171 | sin | 0.0 | 0.06323264771877748 | 1.1 | D140 | 140.0 | 10.0 | False | never returns to hole | 0.0 | 0 | 0.0 | 0.7896834911980527 | -inf | -inf | -inf | 0.0 | 0.0 | 0.22523680128692233 | 0.0 |  |  |  | 0.0 | False
0.08311717542889888 | 0.20790472334344443 | 1.0 | one_inch | CM254-025-M01 | 50.0 | 9 | 4 | 40.940000000000225 | 153 | sin | 0.0 | 0.056573461829994544 | 1.1 | D140 | 140.0 | 10.0 | False | never returns to hole | 0.0 | 0 | 0.0 | 3.782374956779544 | -inf | -inf | -inf | 0.0 | 0.0 | 0.23162153586922957 | 0.0 |  |  |  | 0.0 | False
0.033796909326500306 | 0.34983760356936155 | 1.0 | one_inch | CM254-200-M01 | 400.0 | 11 | 3 | 51.880000000000386 | 187 | sin | 0.0 | -0.04335516558567052 | 1.1 | D140 | 140.0 | 10.0 | False | never returns to hole | 0.0 | 0 | 0.0 | 3.171678092093931 | -inf | -inf | -inf | 0.0 | 0.0 | 0.354778903665091 | 0.0 |  |  |  | 0.0 | False
0.05661358031535067 | 0.3463448468602043 | 1.0 | one_inch | CM254-200-M01 | 400.0 | 11 | 3 | 49.76000000000035 | 209 | sin | 0.0 | 0.051953836488600365 | 1.1 | D140 | 140.0 | 10.0 | False | never returns to hole | 0.0 | 0 | 0.0 | 1.8279723078364527 | -inf | -inf | -inf | 0.0 | 0.0 | 0.3510308605747766 | 0.0 |  |  |  | 0.0 | False
0.05831444223738186 | 0.33248082548783936 | 1.0 | one_inch | CM254-150-M01 | 300.0 | 9 | 4 | 45.700000000000294 | 243 | sin | 0.0 | 0.042181606039920605 | 1.1 | D140 | 140.0 | 10.0 | False | never returns to hole | 0.0 | 0 | 0.0 | 0.7200600881126341 | -inf | -inf | -inf | 0.0 | 0.0 | 0.3400330024243844 | 0.0 |  |  |  | 0.0 | False
0.05665916135702316 | 0.2 | 1.0 | one_inch | CM254-050-M01 | 100.0 | 9 | 4 | 50.30000000000036 | 315 | sin | 0.0 | 0.08096417808191528 | 1.1 | D140 | 140.0 | 10.0 | False | never returns to hole | 0.0 | 0 | 0.0 | 2.672992615365947 | -inf | -inf | -inf | 0.0 | 0.0 | 0.2387550280316115 | 0.0 |  |  |  | 0.0 | False
0.0 | 0.2 | 1.0 | one_inch | CM254-050-M01 | 100.0 | 10 | 3 | 45.82000000000029 | 250 | cos | 7.829083772380845 | -0.07549918931731038 | 1.1 | D140 | 140.0 | 10.0 | False | never returns to hole | 0.0 | 0 | 0.0 | 5.301271500094658 | -inf | -inf | -inf | 0.0 | 0.0 | 0.22253581190919813 | 0.0 |  |  |  | 0.0 | False
0.0 | 0.2 | 1.0 | one_inch | CM254-050-M01 | 100.0 | 11 | 2 | 47.700000000000344 | 275 | cos | 5.9564273977995486 | -0.07996469600752569 | 1.1 | D140 | 140.0 | 10.0 | False | ray died at bounce 1 (clipped) | 0.0 | 0 | 0.0 | inf | -inf | -inf | -inf | 0.0 | 0.0 | 0.2112073974869421 | 0.0 |  |  |  |  | False
0.10952086821107633 | 0.27999999999999997 | 1.0 | one_inch | CM254-050-M01 | 100.0 | 11 | 2 | 48.20000000000035 | 253 | sin | 0.0 | -0.11100163345778834 | 1.1 | D140 | 140.0 | 10.0 | False | ray died at bounce 1 (clipped) | 0.0 | 0 | 0.0 | inf | -inf | -inf | -inf | 0.0 | 0.0 | 0.28425492182268136 | 0.0 |  |  |  |  | False
0.047267194808447176 | 0.23270448068281538 | 1.0 | one_inch | CM254-150-M01 | 300.0 | 10 | 3 | 50.840000000000366 | 370 | sin | 0.0 | -0.05647070385431082 | 1.1 | D140 | 140.0 | 10.0 | False | never returns to hole | 0.0 | 0 | 0.0 | 1.441284765869567 | -inf | -inf | -inf | 0.0 | 0.0 | 0.2506207936654103 | 0.0 |  |  |  | 0.0 | False
0.0 | 0.2 | 1.0 | one_inch | CM254-025-M01 | 50.0 | 9 | 2 | 47.800000000000324 | 171 | cos | 4.969761310446701 | -0.023695582327742458 | 1.1 | D140 | 140.0 | 10.0 | False | never returns to hole | 0.0 | 0 | 0.0 | 1.0238815734178528 | -inf | -inf | -inf | 0.0 | 0.0 | 0.21573565368887043 | 0.0 |  |  |  | 0.0 | False
0.10302677811120703 | 0.2 | 1.0 | one_inch | CM254-050-M01 | 100.0 | 11 | 3 | 47.240000000000315 | 253 | sin | 0.0 | -0.08278977042326115 | 1.1 | D140 | 140.0 | 10.0 | False | never returns to hole | 0.0 | 0 | 0.0 | 0.7093554575337165 | -inf | -inf | -inf | 0.0 | 0.0 | 0.2209809169359523 | 0.0 |  |  |  | 0.0 | False
0.06425631710451543 | 0.2550941010802772 | 1.0 | one_inch | CM254-025-M01 | 50.0 | 11 | 4 | 46.26000000000032 | 143 | sin | 0.0 | -0.0346921657240016 | 1.1 | D140 | 140.0 | 10.0 | False | never returns to hole | 0.0 | 0 | 0.0 | 2.8720245795331976 | -inf | -inf | -inf | 0.0 | 0.0 | 0.2694725638449356 | 0.0 |  |  |  | 0.0 | False
0.0 | 0.2 | 1.0 | one_inch | CM254-050-M01 | 100.0 | 11 | 2 | 48.30000000000035 | 473 | cos | 8.689575183952964 | 0.11526537448722889 | 1.1 | D140 | 140.0 | 10.0 | False | ray died at bounce 1 (clipped) | 0.0 | 0 | 0.0 | inf | -inf | -inf | -inf | 0.0 | 0.0 | 0.2114834099015256 | 0.0 |  |  |  |  | False
0.0 | 0.2 | 1.0 | one_inch | CM254-050-M01 | 100.0 | 11 | 2 | 48.00000000000035 | 451 | cos | 8.294167828886954 | 0.11068252081053985 | 1.1 | D140 | 140.0 | 10.0 | False | ray died at bounce 1 (clipped) | 0.0 | 0 | 0.0 | inf | -inf | -inf | -inf | 0.0 | 0.0 | 0.21134501748274542 | 0.0 |  |  |  |  | False
0.0 | 0.2 | 1.0 | one_inch | CM254-050-M01 | 100.0 | 11 | 2 | 48.30000000000035 | 385 | cos | 7.119719747234636 | 0.09444157459211885 | 1.1 | D140 | 140.0 | 10.0 | False | ray died at bounce 1 (clipped) | 0.0 | 0 | 0.0 | inf | -inf | -inf | -inf | 0.0 | 0.0 | 0.2114834099015256 | 0.0 |  |  |  |  | False
0.1314710570439734 | 0.24627285973678054 | 1.0 | one_inch | CM254-025-M01 | 50.0 | 11 | 3 | 47.82000000000034 | 187 | sin | 0.0 | -0.02374961175073938 | 1.1 | D140 | 140.0 | 10.0 | False | never returns to hole | 0.0 | 0 | 0.0 | 0.5128268563473425 | -inf | -inf | -inf | 0.0 | 0.0 | 0.2581074972269608 | 0.0 |  |  |  | 0.0 | False
0.13398810225708474 | 0.27999999999999997 | 1.0 | one_inch | CM254-050-M01 | 100.0 | 11 | 2 | 48.20000000000035 | 297 | sin | 0.0 | -0.13579967413864438 | 1.1 | D140 | 140.0 | 10.0 | False | ray died at bounce 1 (clipped) | 0.0 | 0 | 0.0 | inf | -inf | -inf | -inf | 0.0 | 0.0 | 0.28425492182268136 | 0.0 |  |  |  |  | False
0.0 | 0.21672741322444827 | 1.0 | one_inch | CM254-025-M01 | 50.0 | 10 | 3 | 47.200000000000315 | 250 | cos | 5.880707392666226 | -0.025291925997770234 | 1.1 | D140 | 140.0 | 10.0 | False | never returns to hole | 0.0 | 0 | 0.0 | 0.8360544906919306 | -inf | -inf | -inf | 0.0 | 0.0 | 0.23574480434638317 | 0.0 |  |  |  | 0.0 | False
0.10556706160255763 | 0.2 | 1.0 | one_inch | CM254-025-M01 | 50.0 | 9 | 2 | 46.760000000000325 | 171 | sin | 0.0 | -0.03163589879935301 | 1.1 | D140 | 140.0 | 10.0 | False | never returns to hole | 0.0 | 0 | 0.0 | 0.5498102261263396 | -inf | -inf | -inf | 0.0 | 0.0 | 0.21508208160075937 | 0.0 |  |  |  | 0.0 | False
0.0 | 0.2 | 1.0 | one_inch | CM254-025-M01 | 50.0 | 10 | 3 | 42.24000000000026 | 210 | cos | 4.6424618536422315 | -0.06449352403014223 | 1.1 | D140 | 140.0 | 10.0 | False | never returns to hole | 0.0 | 0 | 0.0 | 1.1213955408397538 | -inf | -inf | -inf | 0.0 | 0.0 | 0.21929966907191153 | 0.0 |  |  |  | 0.0 | False
0.10872065874871138 | 0.2 | 1.0 | one_inch | CM254-050-M01 | 100.0 | 11 | 2 | 47.92000000000034 | 275 | sin | 0.0 | 0.11073231375917629 | 1.1 | D140 | 140.0 | 10.0 | False | ray died at bounce 34 (clipped) | 0.0 | 0 | 0.0 | inf | -inf | -inf | -inf | 0.0 | 0.0 | 0.21130824322893915 | 0.0 |  |  |  |  | False
0.11149524797607488 | 0.21672741322444827 | 1.0 | one_inch | CM254-025-M01 | 50.0 | 10 | 3 | 46.26000000000032 | 250 | sin | 0.0 | -0.03768349546998242 | 1.1 | D140 | 140.0 | 10.0 | False | never returns to hole | 0.0 | 0 | 0.0 | 1.3766230264440211 | -inf | -inf | -inf | 0.0 | 0.0 | 0.23502402091686084 | 0.0 |  |  |  | 0.0 | False
0.0 | 0.2 | 1.0 | one_inch | CM254-050-M01 | 100.0 | 10 | 3 | 46.400000000000325 | 370 | cos | 5.752942116188012 | 0.10594620983581826 | 1.1 | D140 | 140.0 | 10.0 | False | ray died at bounce 108 (clipped) | 0.0 | 0 | 0.0 | inf | -inf | -inf | -inf | 0.0 | 0.0 | 0.22308021285902468 | 0.0 |  |  |  |  | False
0.0 | 0.24640713256943284 | 1.0 | one_inch | CM254-025-M01 | 50.0 | 11 | 4 | 45.50000000000031 | 143 | cos | 7.513376450249263 | 0.04247113259944657 | 1.1 | D140 | 140.0 | 10.0 | False | never returns to hole | 0.0 | 0 | 0.0 | 6.461254864992403 | -inf | -inf | -inf | 0.0 | 0.0 | 0.26179513910797597 | 0.0 |  |  |  | 0.0 | False
0.09504845802274747 | 0.2 | 1.0 | one_inch | CM254-050-M01 | 100.0 | 11 | 2 | 48.74000000000035 | 209 | sin | 0.0 | 0.09641277829272708 | 1.1 | D140 | 140.0 | 10.0 | False | ray died at bounce 107 (clipped) | 0.0 | 0 | 0.0 | inf | -inf | -inf | -inf | 0.0 | 0.0 | 0.2116877795077302 | 0.0 |  |  |  |  | False
0.0 | 0.2 | 1.0 | one_inch | CM254-075-M01 | 150.0 | 10 | 3 | 44.60000000000028 | 290 | cos | 5.3531204582636756 | 0.0973409774868687 | 1.1 | D140 | 140.0 | 10.0 | False | never returns to hole | 0.0 | 0 | 0.0 | 2.513924753665085 | -inf | -inf | -inf | 0.0 | 0.0 | 0.22140881664627213 | 0.0 |  |  |  | 0.0 | False
0.10277845000233668 | 0.2 | 1.0 | one_inch | CM254-025-M01 | 50.0 | 9 | 2 | 41.46000000000026 | 207 | sin | 0.0 | -0.07499499405335608 | 1.1 | D140 | 140.0 | 10.0 | False | never returns to hole | 0.0 | 0 | 0.0 | 4.389811522948196 | -inf | -inf | -inf | 0.0 | 0.0 | 0.21194712443476985 | 0.0 |  |  |  | 0.0 | False
0.0 | 0.2 | 1.0 | one_inch | CM254-050-M01 | 100.0 | 11 | 2 | 50.14000000000035 | 209 | cos | 4.049929979237793 | 0.05393678771130783 | 1.1 | D140 | 140.0 | 10.0 | False | never returns to hole | 0.0 | 0 | 0.0 | 1.0743402683691183 | -inf | -inf | -inf | 0.0 | 0.0 | 0.21234902371057626 | 0.0 |  |  |  | 0.0 | False
0.0 | 0.2 | 1.0 | one_inch | CM254-050-M01 | 100.0 | 11 | 2 | 48.20000000000035 | 297 | cos | 5.565520046528185 | 0.07397324710643446 | 1.1 | D140 | 140.0 | 10.0 | False | ray died at bounce 42 (clipped) | 0.0 | 0 | 0.0 | inf | -inf | -inf | -inf | 0.0 | 0.0 | 0.21143719336394123 | 0.0 |  |  |  |  | False
0.03132715411160247 | 0.278218873282213 | 1.0621535370053685 | one_inch | CM254-250-M01 | 500.0 | 12 | 5 | 53.485093866134605 | 132 | sin | -0.068777642917145 | 0.033729380371211634 | 1.1 | D150 | 150.0 | 12.0 | True |  | 13.638937109426905 | 132 | 0.8771602801486917 | 1.195123121976367e-06 | 0.6464267432926403 | 3.3754988987287913 | 0.8674911075086402 | 1.536218299015579 | 0.34105354400534527 | 0.29696531438907037 | 16.817836758002578 | 0.7859931075364709 | 0.800515925894512 | 15.030950796376361 | 0.0 | True | 142.9701877322692
0.05636107763760012 | 0.2 | 1.2159530923732096 | one_inch | CM254-050-M01 | 100.0 | 12 | 5 | 52.39151502653029 | 132 | sin | -0.42459668073529455 | 0.050922289560158956 | 1.1 | D150 | 150.0 | 12.0 | True |  | 13.360085811817003 | 132 | 0.8770800738448549 | 0.0017402757622780147 | 1.6251707723001556 | 3.606481130129299 | 0.3510419848872919 | 0.9326493332524616 | 0.33927818209252963 | 0.2573702186670615 | 17.339438607084773 | -0.04859838195256194 | 0.02277067060041582 | 15.11576432763905 | 0.0 | True | 140.7830300530606
0.0021590199125305553 | 0.2756803966047527 | 0.8694167346369366 | one_inch | CM254-050-M01 | 100.0 | 12 | 5 | 51.738836958348884 | 180 | cos | 5.103810146973663 | -0.05003553680798464 | 1.1 | D150 | 150.0 | 12.0 | True |  | 17.991308177996718 | 180 | 0.8360310213469474 | 5.996632589497809e-08 | 0.48706018175294696 | 5.735422880584288 | 1.1179604886728862 | 2.0133295829332214 | 0.48702508311042814 | 0.28789789001727845 | 17.167530920017974 | -0.03535812584697817 | 0.035376671213470656 | 15.145475989449144 | 0.0 | True | 139.47767391669777
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

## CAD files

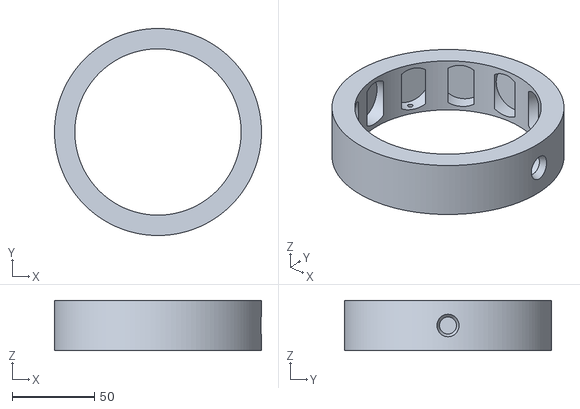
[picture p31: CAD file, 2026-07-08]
_CURRENT/drone_20m/designs/cad/tmpc_14cm_hybrid_cartridge_al.stl
125.6 x 125.5 x 30.6

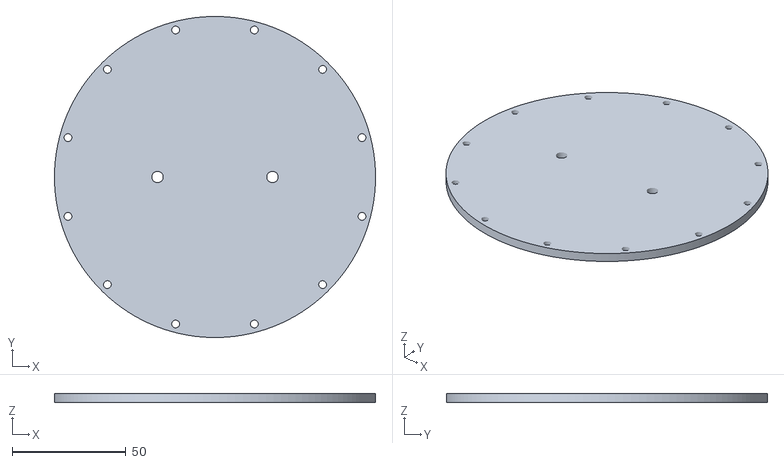
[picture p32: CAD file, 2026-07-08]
_CURRENT/drone_20m/designs/cad/tmpc_14cm_hybrid_lid_plastic.stl
140.9 x 140.8 x 4.00

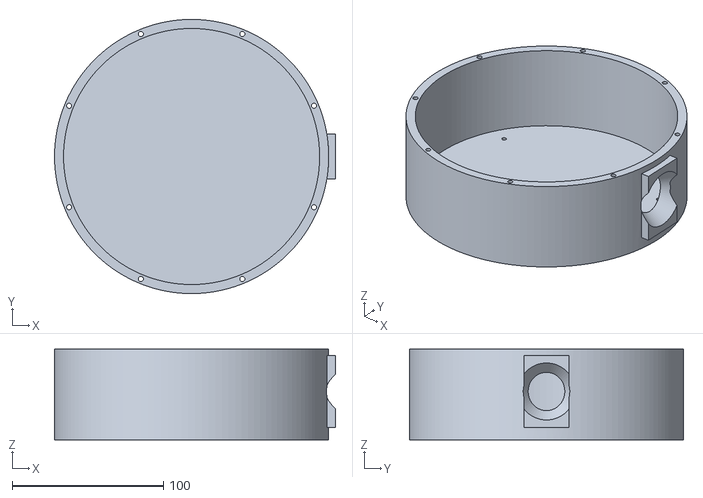
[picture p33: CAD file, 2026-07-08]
_CURRENT/drone_20m/designs/cad/tmpc_19m_2in_hybrid_shell_plastic.stl
186.1 x 181.5 x 60.0

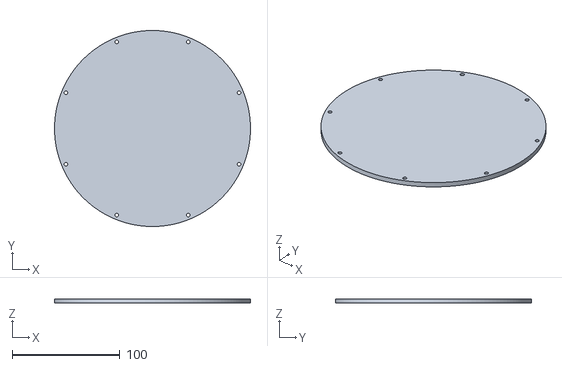
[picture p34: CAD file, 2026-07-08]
_CURRENT/drone_20m/designs/cad/tmpc_19m_2in_lid.stl
181.6 x 181.5 x 4.00

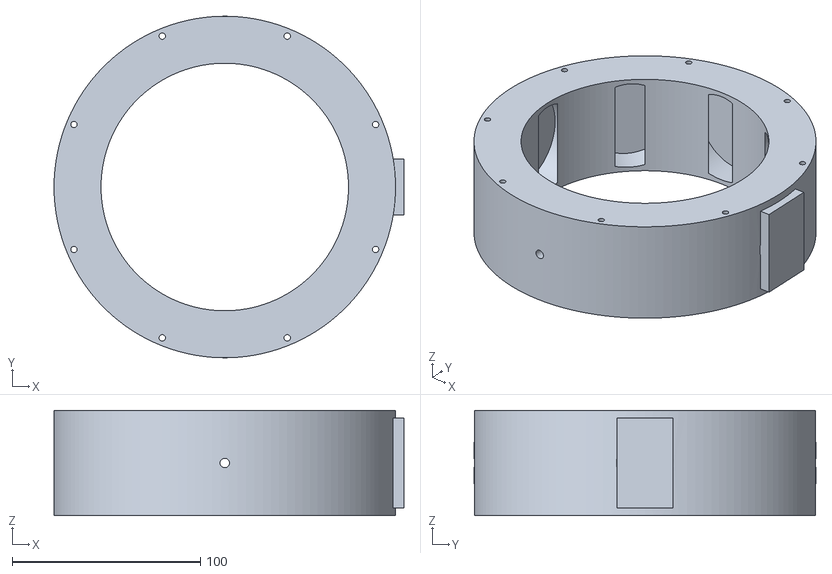
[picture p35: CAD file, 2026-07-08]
_CURRENT/drone_20m/designs/cad/tmpc_19m_2in_ring_body.stl
186.1 x 181.6 x 56.0

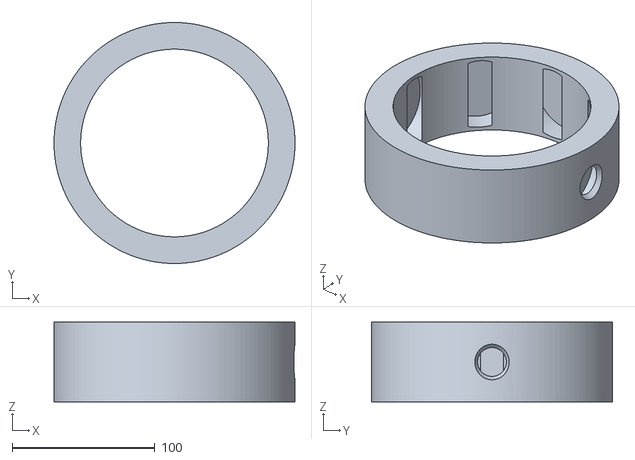
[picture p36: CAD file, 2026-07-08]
_CURRENT/drone_20m/designs/cad/tmpc_19m_2in_hybrid_cartridge_al.stl
169.0 x 168.9 x 56.0

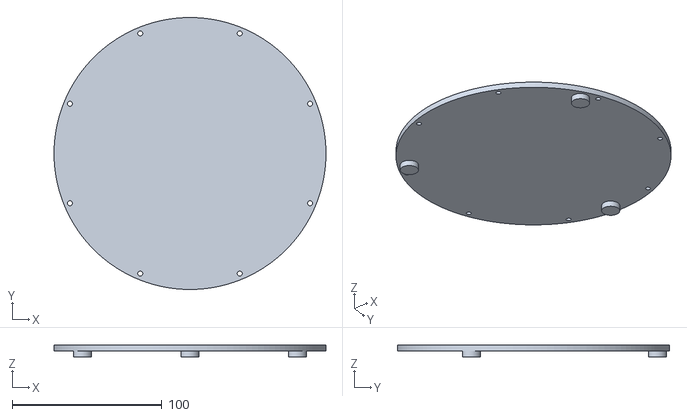
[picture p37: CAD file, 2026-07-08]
_CURRENT/drone_20m/designs/cad/tmpc_19m_2in_base.stl
181.6 x 181.5 x 8.00

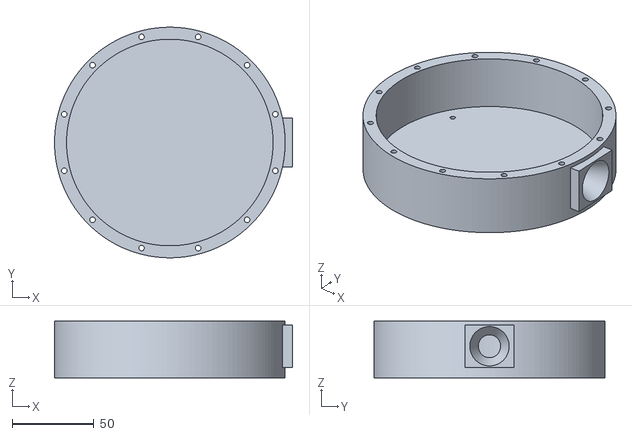
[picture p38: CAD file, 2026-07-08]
_CURRENT/drone_20m/designs/cad/tmpc_14cm_hybrid_shell_plastic.stl
145.4 x 140.8 x 34.6

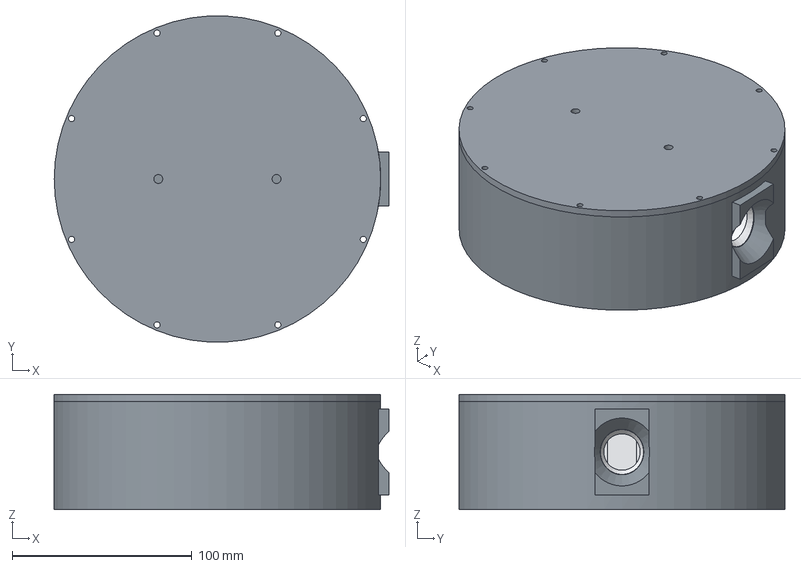
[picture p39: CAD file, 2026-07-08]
_CURRENT/drone_20m/designs/cad/tmpc_19m_2in_hybrid.step
186.1 x 181.3 x 64.0 mm
shell_plastic
cartridge_al
lid_plastic

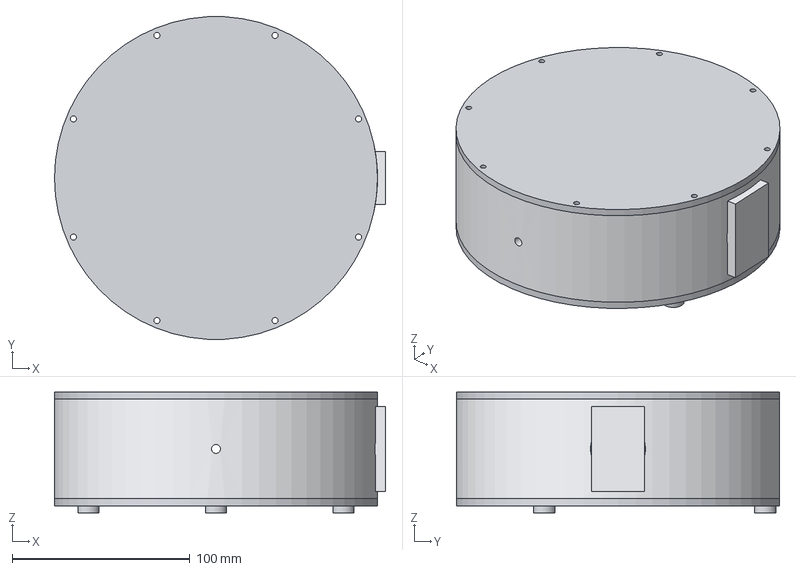
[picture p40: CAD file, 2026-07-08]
_CURRENT/drone_20m/designs/cad/tmpc_19m_2in.step
186.1 x 181.6 x 68.0 mm
ring_body
lid
base

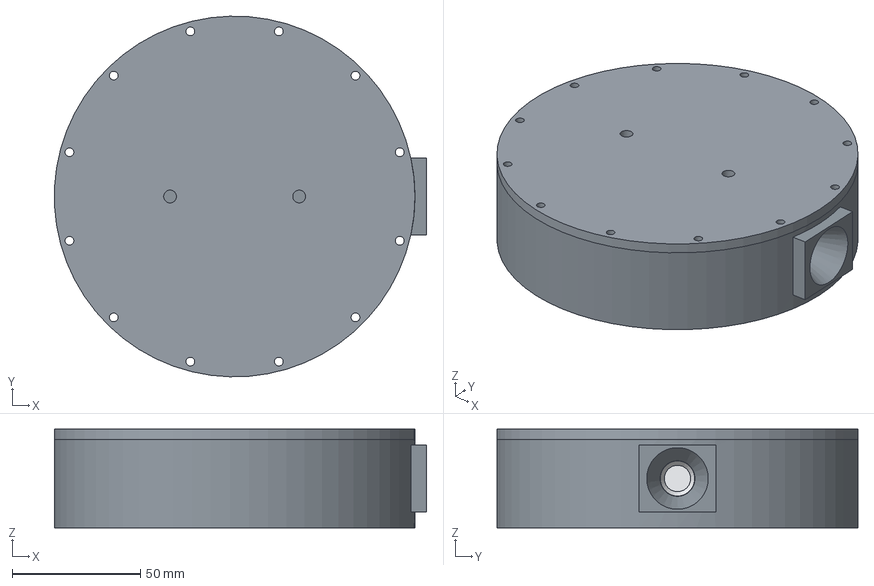
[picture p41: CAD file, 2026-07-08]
_CURRENT/drone_20m/designs/cad/tmpc_14cm_hybrid.step
145.3 x 140.8 x 38.6 mm
shell_plastic
cartridge_al
lid_plastic

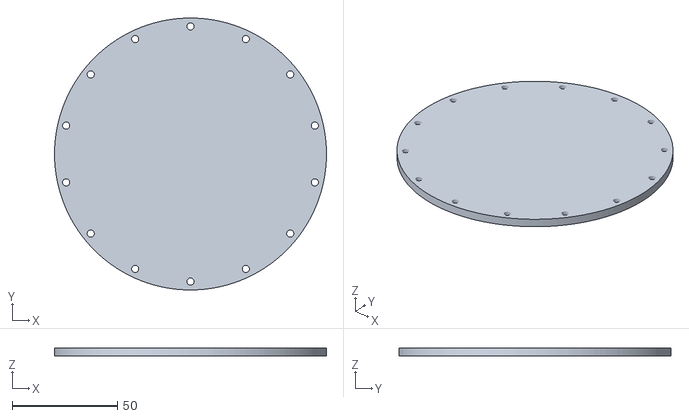
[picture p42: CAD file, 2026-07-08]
_CURRENT/drone_20m/designs/cad/tmpc_9m_mini_lid.stl
129.2 x 129.2 x 4.00

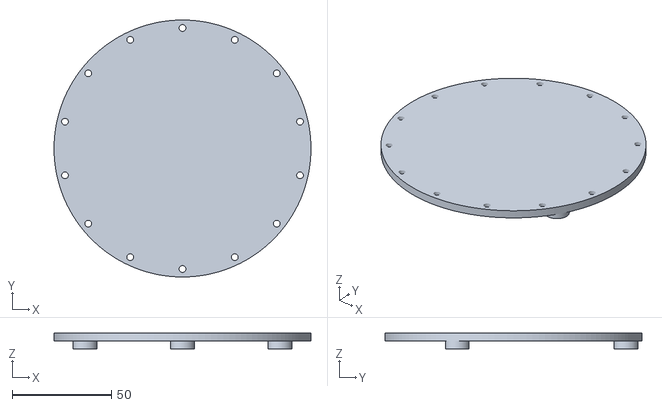
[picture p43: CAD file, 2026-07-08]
_CURRENT/drone_20m/designs/cad/tmpc_9m_mini_base.stl
129.2 x 129.2 x 8.00

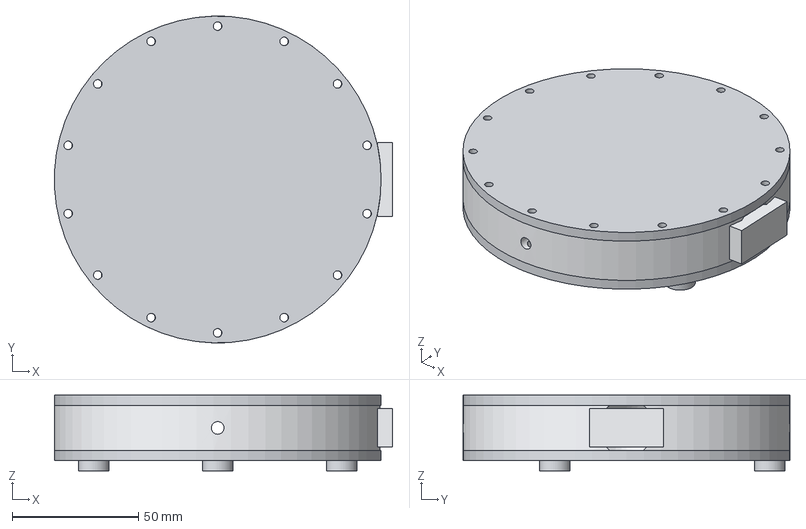
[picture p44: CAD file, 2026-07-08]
_CURRENT/drone_20m/designs/cad/tmpc_9m_mini.step
133.6 x 129.2 x 29.9 mm
ring_body
lid
base

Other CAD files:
_CURRENT/drone_20m/designs/cad/tmpc_19m_2in_hybrid_lid_plastic.stl
_CURRENT/drone_20m/designs/cad/tmpc_9m_mini_ring_body.stl
_CURRENT/drone_20m/designs/cad/tmpc_29m_ring_body.stl
_CURRENT/drone_20m/designs/cad/tmpc_14cm_base.stl
_CURRENT/drone_20m/designs/cad/tmpc_14cm.step
_CURRENT/drone_20m/designs/cad/tmpc_14cm_lid.stl
_CURRENT/drone_20m/designs/cad/tmpc_14cm_ring_body.stl
_CURRENT/drone_20m/designs/cad/tmpc_20m.step
_CURRENT/drone_20m/designs/cad/tmpc_20m_base.stl
_CURRENT/drone_20m/designs/cad/tmpc_20m_lid.stl
_CURRENT/drone_20m/designs/cad/tmpc_20m_ring_body.stl
_CURRENT/drone_20m/designs/cad/tmpc_29m.step
_CURRENT/drone_20m/designs/cad/tmpc_29m_base.stl
_CURRENT/drone_20m/designs/cad/tmpc_29m_lid.stl

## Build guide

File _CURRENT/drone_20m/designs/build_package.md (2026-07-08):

# Build package — tri-gas flagship (25.7 m) and standard-build (20.4 m) cells

*(Executes the paper's first next step up to the purchase order and the
bench: complete BOM, critical dimensions with tolerances, assembly and
alignment procedure. Companion documents:
[experimental_protocol.md](experimental_protocol.md) for acceptance
tests, [flight_system_plan.md](flight_system_plan.md) for the airborne
integration. CAD: [cad/](cad/); per-design machining numbers:
[spec_D190_26m.md](spec_D190_26m.md), spec_D190_maxT / drone_20m sheets.)*

## 1. Bill of materials

| # | item | part | qty | ~unit USD | notes |
|---|---|---|---|---|---|
| 1 | concave mirrors (flagship) | Thorlabs CM254-200-M01 (ROC 400) | 16 | 74 | one lot; record lot # |
| 1′ | concave mirrors (standard cell) | CM254-150-M01 (ROC 300) | 16 | 74 | |
| 2 | drilled mirror M0 | one of item 1 modified: Ø2.6 mm bore, rear countersink 60° to Ø6 | 1 | ~80 svc | ultrasonic/diamond drill from rear; ≤0.5 mm coated land removed at edge |
| 3 | ring housing | Al 6061-T6, from Ø200×40 stock; machine per §2 | 1 | 250–600 CNC | single-setup pockets |
| 4 | lid + base | Al 6061, 4 mm plates per CAD | 2 | incl. | O-ring groove per CAD DFM pass |
| 5 | window (CH₄+NH₃) | Thorlabs WW10530-C (Ø1/2″ UVFS wedged, 1050–1700 AR) | 1 | ~90 | |
| 6 | window (CH₄+H₂) | Thorlabs WW30530-D (Ø1/2″ sapphire wedged, 1.65–3.0 µm AR) | 1 | ~150 | c-cut; verify -D curve at 1653.7 nm on the test report |
| 7 | window O-ring | FKM, Ø12 × 1 mm section | 2 | 1 | NH₃-compatible (not NBR) |
| 8 | fibre collimator + mode-match lens | adjustable FC/APC collimator with f ≈ 2 mm asphere (collimation-package class) | 1 | 120 | focus ring = alignment trim; conjugates on spec sheet |
| 9 | alternative first stage | reflective OAP fibre collimator (protected silver/gold) | 1 | 400 | athermal, serves all three λ |
| 10 | laser (CH₄) | Eblana EP1654-DM (fibre-pigtailed DFB) | 1 | ~2k | |
| 11 | laser (NH₃) | Eblana EP1512-DM | 1 | ~2k | |
| 12 | laser (H₂) | Nanoplus / LD-PD 2122 nm DFB, PM pigtail | 1 | ~4k | PM key aligned sagittal (§6.6 of paper) |
| 13 | detector (CH₄/NH₃) | standard InGaAs, Ø1 mm class | 1 | 150 | |
| 14 | detector (H₂) | extended InGaAs (Thorlabs FD05D class) + f = 15–25 mm lens | 1 | 250 | lens mandatory (drift budget) |
| 15 | mirror adhesive | 3M/Loctite Hysol EA 9313 class | — | 40 | 20–40 g shock qual |
| 16 | ring heater + RTD | 10–20 W foil heater + PT100 + TEC-style PI loop | 1 | 120 | trim + anti-dew |
| 17 | dampers | 4× rubber isolators, 40–60 Sh A, sized to ~1.5 kg | 4 | 30 | between cell plate and airframe |
| 18 | gas fittings | 2× M5/barb + PTFE line | 2 | 20 | |

Optics + housing subtotal ≈ US$2.3–2.9k per cell excluding lasers.

## 2. Critical dimensions and callouts (flagship; standard cell in brackets)

| feature | value | tolerance / callout |
|---|---|---|
| ring radius R_ring (pocket-seat datum to axis) | **74.507 mm** [72.155] | ±0.020 machining; final value from §3 step 2 trim law |
| pocket azimuths | 16 × 22.500° | ±0.01° (single-setup rotary) |
| pocket seat plane | ⊥ radial axis at R_ring + 6.35 | flatness 0.010 mm over Ø25.6 (= 0.4 mrad); precision tier: lap to 0.003 |
| pocket bore | Ø25.50 H7, depth 7.0 | mirror is bonded, not pressed: 3 adhesive dots |
| M0 bore in housing | cone per CAD, half-angle AOI + 8° = 19.4° [19.3°] | window boss ⊥ bisector |
| coupling hole in mirror | Ø2.60 ±0.05, at face centre + (0, +0.338 mm) [(0, +0.543)] sagittal offset | position ±0.05; rear countersink |
| cavity bore | Ø(2·R_ring − 4) | ±0.1 |
| envelope | Ø185.0 [Ø180.3] × 33 h | — |
| gas ports | 2 × M5 at 90°/270° | — |
| lid/base bolt circle | 16 × M3 on Ø(R_ring + 12) | — |

## 3. Assembly & alignment procedure

1. **Incoming metrology.** Measure every mirror's ROC (autocollimator/
   interferometer, ±0.1 % goal); record per serial. Compute lot-mean ROC
   error ε [%].
2. **Ring trim law.** Machine R_ring = design value + 0.750·ε mm
   [0.72·ε]. (Linear law verified over ±1 %; interpolate freely.)
3. **Mirror bonding.** Bond 15 stock mirrors + the drilled M0 into
   pockets (3-dot epoxy, cure per datasheet, no clamping stress). M0's
   hole offset is oriented to the sagittal (+z) axis; scribe mark up.
4. **Window + ports.** Fit wedged window on the boss, wedge apex
   sagittal, boss gives the 3–5° tilt; torque lid/base with O-rings;
   leak-check to <10⁻³ mbar·L/s (soap/pressure decay is sufficient for
   flow-through use).
5. **Launch bench.** Mount collimator on the boss bracket; set the
   collimator focus to the spec-sheet conjugate (flagship: waist 0.295 mm
   at 72.3 mm past the hole; standard: 0.326 mm at 102 mm). Feed with
   the CH₄ DFB first regardless of target gas (visible on standard
   InGaAs card + strongest margins).
6. **First light.** Align launch tilts to the spec-sheet values (mrad
   entries) using the two adjuster screws; look for the exit spot at
   2×AOI (22.6–22.7°) behind M0 — target the quadrant/photodiode centre.
   Expected transmitted power at R = 0.999 lot: 83.9 % [86.7 %] ×
   window/collimator losses (~3–5 %).
7. **Ring-temperature walk-in.** With the PI loop, scan ring temperature
   ±3 K in 0.2 K steps while logging transmission: the closure peak is
   the setpoint (gain 1.7 µm/K ≈ 60 µrad of accumulated phase per K).
   Lock. This absorbs the final machining residual.
8. **Freeze.** Torque-seal the launch adjusters. For flight: verify the
   assembly passes the §experimental_protocol vibration profile with
   <5 % transmission modulation.
9. **Gas-line swap procedure.** Change laser + detector (+ window if
   moving to/from H₂); rescale collimator focus by √(λ₂/λ₁) (one ring
   turn — values on spec sheet); re-run step 7. No mechanical
   realignment of mirrors is required (Monte-Carlo verdicts in paper
   Table 7).

## 4. Acceptance gates (details in experimental_protocol.md)

* transmission within −5 % absolute of R^(n−1) × chain losses,
* exit spot within 1 mm of nominal position at 50 mm,
* fringe floor: NEA ≤ 1×10⁻⁴ direct / ≤ 1×10⁻⁵ WMS at 1 s,
* no chord-FSR-spaced structure (0.034 cm⁻¹) above 3× baseline noise,
* polarization purity ≥ 95 % sagittal-in/sagittal-out,
* thermal: lock holds over ±10 K ambient with heater authority to spare.

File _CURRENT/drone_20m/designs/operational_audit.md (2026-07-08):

# Operational physics audit — polarization, vibration, and everything else

*(Closes the "all aspects" loop for the paper: every effect a referee
may probe, either analyzed with numbers or bounded and dismissed with
numbers. Data: [polarization_audit.csv](polarization_audit.csv),
[mc400_new_designs.csv](mc400_new_designs.csv), tolerance-run
sensitivity tables.)*

## 1. Polarization (exact Jones-matrix accumulation over the traced path)

Over 98–204 gold reflections the s/p Fresnel differences accumulate, and
the sagittal launch tips the incidence plane slightly bounce-to-bounce.
Computed with complex-index Fresnel coefficients (bare-gold constants,
Babar & Weaver; the protective/enhancement dielectric perturbs ratios at
the <10⁻³/bounce level) along the exact traced geometry:

| design | AOI | s-launch purity at exit | 45°-launch exit ellipticity | s/p split (bare-gold worst case) |
|---|---|---|---|---|
| 20.4 m Ø180 (drone_20m) | 11.3° | **99.3 %** | 30° | ×1.13 over path |
| 25.7 m Ø185 (tri-gas) | 11.4° | **99.6 %** | 37° | ×1.17 |
| 15.3 m Ø175 (sparse) | 11.3° | **99.3 %** | 24° | ×1.10 |
| 20.7 m Ø141 (drone_14cm) | 15.1° | 96.3 % | 13° | ×1.33 |
| 9.1 m Ø129 (½″ mini) | 25.7° | **99.8 %** | −19° | ×1.57 |
| 14.9 m Ø133 (skip-3) | **36.0°** | 99.9 % | 6° | **×6.4** |

Design rules that follow:

1. **Launch linearly polarized along the sagittal (vertical) axis.** The
   incidence planes stay near-horizontal for the whole pattern, so s is
   an eigenaxis: s-launched light exits 96.3–99.9 % pure in every
   design. Fiber chain: use PM fiber keyed to sagittal, or a polarizer
   at the collimator.
2. **Do not put polarization-analyzing optics after the cell.** A 45°
   launch exits 6–39° elliptical (accumulated metallic retardance) with
   pattern-specific azimuth rotation — harmless for direct detection on
   a photodiode (our chain), hazardous for any polarization-filtered
   receive path.
3. The high-AOI skip-3 family (36°) is strongly diattenuating (up to
   ×6.4 s/p in bare-gold worst case; ~×1.1 rescaled to an R = 0.999
   coating) — one more reason the near-diameter (low-AOI) chord-skip
   family is the right architecture, and a quantitative novelty for the
   paper (polarization behaviour of dense re-entrant rings is not in
   the literature).

## 2. Vibration → signal budget ("will shaking show up in the spectra?")

Chain, at the ArduPilot-class operational level (1.5–3 g RMS broadband,
60–700 Hz; rubber dampers between airframe and cell at transmissibility
0.1–0.3 above 100 Hz per the flight-proven Empa configuration → 0.2–1 g
at the cell):

| link | magnitude | vs budget |
|---|---|---|
| elastic seat tilt, monolithic Al ring @1 g | stress ρgh ≈ 0.8 kPa → strain 1.2×10⁻⁸ → **0.01–0.1 µrad** | flight tilt budget 100 µrad: margin >10³ |
| resonant amplification | lid f₁ = 1.2–2.0 kHz (Al) is **above** the 60–700 Hz band; worst in-band Q≈50 edge case ≤ 10 µrad | margin >10 |
| ring radius modulation @1 g | <10 nm elastic | closure valley ±100 µm: margin 10⁴ |
| launch-chain pointing (collimator cantilever) | 1–10 µrad @1 g (kHz-class barrel modes) | MC launch-tilt σ = 100 µrad contributes ≲10 % of walk: vibration adds ~1 % |
| exit-spot jitter on detector | dominant *residual*: µrad-scale pointing × lever ≈ µm-scale spot motion | focus the exit (f ≤ 25 mm lens) and overfill margin; quad feedback in the active tier |
| aero-optic (rotor-wash δp ≈ 50 Pa) | δn ≈ 1.3×10⁻⁷ → δOPL ≈ 2.6 µm at 20 m, sub-10 Hz | common-mode baseline; invisible to WMS, fitted in DA |
| acoustic excitation of windows | wedged 3 mm windows, first modes ≫10 kHz | negligible |

Conclusion (matches the Empa flight finding): with the cell rigid inside
and damped outside, **vibration couples to the signal through the launch
and detector chain, not through the ring optics** — the mitigation is a
short stiff collimator boss (in the CAD), a focusing lens at the
detector, and dampers under the whole assembly. Numbers above give a
referee the margins; the Fusion-360 modal study on the shipped STEP is
the confirmation step for the specific machined part.

## 3. Remaining effects, bounded

* **Gravity/orientation sag**: ring self-weight deflection <0.5 µm; a
  90° attitude change re-orients it — absorbed by the walk budget
  (±100 µm class); re-zeroed by the standard trim anyway.
* **Mirror surface quality**: split correctly for the reviewer —
  low-order figure error (catalog λ/10 irregularity) is power/astigmatism
  → already Monte-Carloed as ROC error (±1 mm σ ≫ spec); Å-class
  polish roughness → TIS ≈ (4πσ/λ)² ≈ 10⁻⁵/bounce → 0.1–0.3 % total
  diffuse scatter over the path — this is precisely the stray-light
  reservoir whose interference the enforced spot separation suppresses
  (see the overlap criterion), closing the loop between surface spec
  and fringe budget.
* **Refractive-index of the sample** (1 atm ↔ vacuum): OPL changes by
  n−1 ≈ 2.7×10⁻⁴ (5.5 mm on 20.4 m) — a calibration constant, not a
  drift; pressure-driven variation is 10⁻⁶-scale.
* **Detector étendue (H₂ channel)**: extended-InGaAs is small (FD05D
  Ø0.5 mm). Exit drift p95 is 2.7–4.3 mrad (1″ designs) and 15.3 mrad
  (½″ mini): an f = 15–25 mm collection lens keeps the focused spot
  within ±0.4 mm — mandatory for the mini + H₂ combination; already in
  the spec-sheet pickoff geometry.
* **Contamination (open-flow mode)**: dust on gold at grazing spots adds
  scatter; mitigation: 10 µm inlet mesh, downward-facing apertures,
  periodic R check via the throughput monitor (T = R^(n−1) makes the
  cell its own reflectometer — a 0.01 % per-mirror change reads as 2 %
  transmission change on 204 bounces).
* **Condensation**: the ring trim heater doubles as an anti-dew heater;
  keep cell a few K above ambient dew point — consistent with the ±18–26
  K thermal windows.
* **Adhesive creep/ageing**: bonded mounts qualified to 20–40 g;
  post-cure creep appears as slow pattern walk — inside the trim
  authority (±10 K heater = ±17 µm ring-equivalent); recalibration
  interval set by the throughput monitor trend.
* **Laser power**: mW-class on Ø0.6 mm spots → W/cm² regime; damage
  thresholds are kW/cm²-class — no thermal lensing on gold at 10⁻³
  absorption of mW.

The paper can therefore claim tolerance coverage across machining,
assembly, coating lot, wavelength, temperature, humidity/moisture,
vibration, orientation, polarization and contamination — each with a
number, a margin, or a designed-in mitigation.

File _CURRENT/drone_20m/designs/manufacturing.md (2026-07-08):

# Manufacturing, weight, vibration and "construction tolerance"

*(Dr. Benoy, 2026-07-08: "Now think how you will design the actual cell in
Fusion 360. Can you design using 3D printing? Or do you need CNC machining?
Using aluminium and various materials, do simulation for weight and
vibration... This is called construction tolerance. Will the gas cell
survive construction tolerance? ... say if we can 3D print something under
200$.")*

<p align="center">
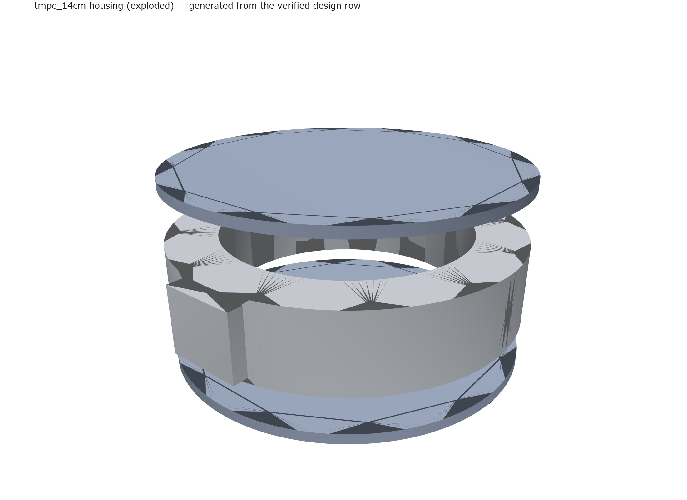
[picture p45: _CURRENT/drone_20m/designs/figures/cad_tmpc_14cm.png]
tmpc_14cm housing CAD render (exploded)
  
  tmpc_20m housing CAD render (exploded)
</p>

*Exploded housing renders generated from the verified design rows
(`housing_cad.py`): mirror pockets on the exact ring radius, mirror-0
beam cone at the design AOI, window boss, gas ports. STEP/STL in
[cad/](cad/).*

## 0. The deliverables

* **Parametric CAD** generated *from the verified optics rows* (ring
  radius, pocket azimuths, seat depth, mirror-0 beam cone at the design
  AOI, window boss, gas ports, bolt circle): [cad/](cad/) contains STEP
  (imports directly into Fusion 360 for DFM/FEA) + STL (print quoting)
  for `tmpc_14cm` (Ø141), `tmpc_20m` (Ø180), `tmpc_29m` (Ø183) —
  regenerate with `housing_cad.py --design {14cm,20m,29m}`. Because the
  CAD is generated from the design row, the optical datums cannot drift
  from the verified optics. Fusion 360 next steps for the team: shell
  the ring where stress allows, add O-ring grooves + window bezel,
  modal + static FEA on the STEP.
* **Construction-tolerance Monte-Carlo** — our exact ray-tracer MC run
  at tolerance grades mapped from published process capabilities:
  [construction_tolerance.csv](construction_tolerance.csv).
* **Materials table** (mass, first mode, thermal window, moisture):
  [materials_table.csv](materials_table.csv).

## 1. Construction tolerance: mapping processes onto the optics

Process capability (vendor/ISO data) mapped to our MC inputs — mirror-seat
tilt σ = seat flatness / 25.4 mm seat; ring radius σ from radial accuracy:

| process | tilt σ [mrad] | R_ring σ [mm] | one-off cost, 180×30 disc |
|---|---|---|---|
| CNC precision + lapped seats ("flight") | 0.1 | 0.02 | $600–1200 |
| CNC standard (ISO 2768-f + callouts) | 0.5 | 0.10 | $250–600 (US); ~half offshore |
| printed body + machined seats (hybrid) | 0.3 | 0.10 | $150–350 |
| SLA industrial (tough resin) | 1.5 | 0.15 | $60–150 |
| MJF/SLS (PA12) | 2.5 | 0.25 | $80–250 |
| FDM (PLA/PETG) | 4.0 | 0.30 | $20–60 |

100-trial exact-trace MC per design per grade (full criteria: path
completes, spots stay separated, intermediate spots clear the hole, exit
leaves the 1.3 mm hole with **no realignment**):

<p align="center">
  construction-tolerance Monte-Carlo per manufacturing process
</p>

| build | drone_20m (20.4 m, 144 chords) | drone_14cm (20.7 m, 204 chords) | drone_29m (29.0 m, 204 chords) |
|---|---|---|---|
| CNC precision | **survives, as-built** (100 %) | **survives, as-built** (100 %) | **survives, as-built** (99 %) |
| CNC standard | completes 100 %, needs one trim (exit walk 0.92+0.48 = 1.40 > 1.3 mm) | dies (54 % completion) | dies (44 %) |
| printed + machined seats | completes 100 %, needs one trim (1.32 vs 1.30 mm — misses by 20 µm) | 75 % completion — no | 68 % — no |
| SLA | 99 % completion but spots merge (sep p05 = 0.20 mm) | 12 % | 11 % |
| MJF/SLS | 74 % | 3 % | 1 % |
| FDM | 31 % | 2 % | 1 % |

**Answer to "will the gas cell survive construction tolerance":**

* The **dense-pattern designs (k = 17, 204 chords) survive only
  precision-CNC aluminium.** That is also the flight build the drone
  needs for vibration anyway — no extra cost is being imposed by the
  optics.
* The **headline 20.4 m design (k = 9, 144 chords) is the
  manufacturing-tolerant member of the menu**: it completes the full
  path at 100 % even on standard CNC and on a printed body with machined
  seats, and fails only the *no-realignment exit* criterion — by 20 µm
  of pattern walk. With the one ring-shim/temperature trim and launch
  alignment that every build performs, both cheap builds are usable lab
  cells. Sparse patterns are the low-cost-manufacturing corner: fewer
  spots per mirror → wider spacing → more walk budget.
* **A fully-printed $200 polymer cell does not survive** — and the
  failure is structural, not just statistical: (a) best industrial SLA
  holds ±0.15 % → ±0.27 mm on a 180 mm part vs our ±0.1 mm ring budget;
  polymer seat surfaces cannot hold 2.5–12.7 µm flatness (0.1–0.5 mrad);
  (b) even a perfectly printed ring drifts out of tolerance in service:
  PA12 CTE ≈ 109 ppm/K shrinks the thermal closure window to ±2–6 K
  (vs ±8–26 K for Al), and PA12 moisture swelling (0.2–0.3 % linear)
  moves the ring radius 42–110 µm with the weather — the whole budget;
  (c) FDM bodies are 98–99 % dense and leak without epoxy infiltration;
  unbaked prints outgas into the absorption volume (SLA is the least bad:
  water-dominated, 1.9×10⁻⁸ mbar demonstrated after bake).
* The literature agrees: published 3D-printed multipass cells succeed
  only at 4–6 cm scale with tolerance-forgiving two-mirror Herriott
  geometries (best: 4.2 m path, 288 ppb CH₄ MDL, Anal. Chem. 2020), and
  the one flight-proven ring cell (Empa SC-MPC on a DJI M600) is
  monolithic CNC aluminium, <200 g bare.

**Where printing IS the right tool:** window bezels, detector/collimator
shrouds, cable/fan ducting, the enclosure, and a $50 FDM fit-check of the
full assembly before committing the CNC order (we ship STLs for exactly
this). A printed *kinematic* variant (printed body + steel balls +
adjuster screws per mirror) can match commercial mounts on repeatability
and would make a fine classroom/lab demonstrator — but it forfeits the
glued/fixed construction the drone vibration environment wants.

## 2. Weight (parametric model, lid+base 4 mm, wall to envelope)

| design | Al 6061 | Mg AZ31B | Ti-6Al-4V | PA12 print | + mirrors/optics included |
|---|---|---|---|---|---|
| drone_20m Ø180 | **1 710 g** | 1 263 g | 2 549 g | 890 g | 16×20 g mirrors + 80 g optics inside all numbers |
| drone_14cm Ø141 | **1 231 g** | 920 g | 1 814 g | 661 g | 12 mirrors |
| drone_29m Ø183 | **1 661 g** | 1 204 g | 2 519 g | 821 g | 12 mirrors |

Notes: these are solid-wall numbers; Fusion-360 shelling/pocketing
typically takes 25–35 % out of the ring and lids (target ≈ 1.1–1.3 kg for
the Ø180 Al cell, ≈ 0.9 kg for Ø141) — well inside a DJI M300/M350-class
payload (2.7 kg). Magnesium saves ~26 % over Al at similar stiffness but
complicates sealing/corrosion; titanium buys thermal window, not mass.
The empty-shell comparison with Empa's 198 g bare ring is not
apples-to-apples — theirs is a bare open ring without lids, windows,
mirrors or ports.

## 3. Vibration (analytic modes + strategy; FEA handoff ready)

First mode of the lid (edge-clamped plate — the softest structural member
of a lid-and-ring build):

| material | drone_20m Ø180 | drone_14cm Ø141 |
|---|---|---|
| Al 6061 | **1 237 Hz** | 2 026 Hz |
| Ti-6Al-4V | 1 241 Hz | 2 033 Hz |
| PA12 | **327 Hz** | 535 Hz |
| PLA | 411 Hz | 674 Hz |
| tough resin | 377 Hz | 618 Hz |

Multirotor excitation is broadband ~60–700 Hz (rotor/blade-pass harmonics
+ frame resonances) at ~1.5–3 g RMS operational levels. **Aluminium lids
sit 2–20× above the excitation band; every printed polymer variant has
its first mode inside it** — a second, independent disqualifier for the
flying polymer cell. Strategy per the flight-proven Empa result: bond or
screw the mirrors rigidly (epoxy-bonded optics qualify to 20–40 g
MIL-STD-810 shock, an order of magnitude above the drone environment) and
isolate the *whole cell* on rubber dampers from the airframe — rigid
inside, damped outside; they saw significant optical noise rigid-mounted
and no measurable effect on dampers. FEA to confirm ring modes and
damper selection runs directly on the shipped STEP in Fusion 360
(simulation workspace, modal + 3 g random-vibe) — flagged for the team
("ask others also to do this analysis").

## 4. Thermal + environment (from the measured Al closure windows)

Ring closure windows scaled by CTE from the measured Al values
(drone_20m ±26 K):

| material | CTE [ppm/K] | drone_20m window | notes |
|---|---|---|---|
| Invar 36 | 1.2 | ±511 K (never limits) | heavy; use only as a ring insert if extreme range needed |
| Ti-6Al-4V | 8.6 | ±71 K | expensive middle ground |
| **Al 6061** | 23.6 | **±26 K** | fine for drone ops with a trim heater |
| PA12 | ~109 | ±6 K + 108 µm moisture swing | fails outdoors |
| PLA/resin | 68–75 | ±8–9 K + creep | fails outdoors |

The compact Ø141 design's Al window is ±8 K → give it the ring trim
heater (already the standard alignment actuator) or a Ti/invar-insert
ring if it must free-run over wide ambient swings.

## 5. Cost reality check

One-off: CNC Al 6061 at standard tolerance costs the *same class* as a
good polymer print at this size ($250–600 US, ~half offshore, vs $80–250
MJF/SLA) — and precision CNC ($600–1200) is the only route that carries
the dense 204-chord designs. Injection molding ($8–10 k tooling,
break-even ≥ ~400 parts) only enters at production quantities, where a
molded *body* + machined seat inserts + the sparse-pattern design is the
plausible low-cost product architecture. So the honest version of the
"$200 cell" vision: **$200 buys the 144-chord sparse design in a hybrid
printed-body/machined-seat build as an indoor instrument with one
alignment; the drone instrument is a $250–1200 CNC aluminium part either
way — and at one-off quantities CNC costs no more than printing.**

Sources: process tolerances Protolabs/Hubs published specs; ISO 2768-2
flatness classes; CTE/moisture EOS PA2200 + engineering handbooks; FDM
porosity + SLA/PEEK outgassing studies (Diamond Light Source, J. Vac.
studies); printed MPC literature (Anal. Chem. 2020; Sens. Act. B 2025);
Empa drone cell AMT 13, 4715 (2020); vibration norms ArduPilot + ISMA
2016 multirotor study; bonded-optics shock quals (SPIE/Hysol EA 9313);
cost benchmarks Xometry/Protolabs/Formlabs public figures. Our MC:
`mech_materials.py` with the platform's exact tracer.

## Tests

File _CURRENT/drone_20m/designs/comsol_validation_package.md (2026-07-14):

# COMSOL mirror-only validation package (toroidal ring port)

> **STATUS: EXECUTED (2026-07-14/15).** Ran on the university COMSOL 6.4
> + Ray Optics seat over the IITD-AD VPN license server. All 9 menu
> designs cross-validate against the exact tracer to **RMS 1.3–8.7 µm /
> worst 2.9–19.7 µm** over 98–228 bounces, with COMSOL independently
> re-exiting the coupling hole to 8–18 µm. Data:
> [comsol/comsol_agreement.csv](comsol/comsol_agreement.csv); the model
> generator/scorer are `comsol_gen.py` / `comsol_extract.py`; figures
> `figures/comsol_agreement.png` and `figures/comsol_raytrace_montage.png`.
> Now in the paper as §6.7 (Table 11, Figs 17–18). The section below
> documents the (now-executed) protocol for reproducibility.

*(Implements Benoy's "COMSOL Ray-Tracing Validation Protocol for
Mirror-Only Multipass Gas-Cell Spot-Pattern Designs" (2026-07-08,
[prof_inputs](prof_inputs/comsol_ray_tracing_validation_protocol_mirror_only.txt))
for the chord-skip N-mirror ring. "No need experiment. No need to model
the cell body." Tools: `comsol_package.py`, `compare_comsol.py`. Data:
[designs/comsol/](comsol/).)*

## What ships in `designs/comsol/`

| file | contents |
|---|---|
| `comsol_geom_<design>.csv` (×9) + `comsol_geom_all.csv` | every mirror's centre (mm), optical-axis normal, sagittal axis, ROC, clear-aperture radius, hole radius (mirror 0), plus a `launch_ray` row: exact entry point + unit direction, w0 (in `sagx`), wavelength mm (`sagy`), expected pass count (`sagz`), nominal OPL m (`roc_mm`). Frame: ring centre = origin, ring plane z = 0, mirror k at 2πk/N. |
| `comsol_perturbations.csv` | alignment-residual regimes (easy/medium/hard) and the two drone architecture envelopes (Al isostatic flexure; hybrid plastic body + Al cartridge) as per-axis maxima for the parametric sweeps. |
| `comsol_runlog_native.csv` | protocol step 7 executed with our exact tracer: nominal + every per-DOF coherent worst case (all mirrors at +max, then −max; each launch DOF at its box edge), 37 runs × 9 designs, in the protocol's run-log format (pass count, path length, edge/hole/exit clearance, PASS/FAIL). This is the reference answer sheet the COMSOL model should reproduce. |

## Building the COMSOL model (10 minutes per design)

1. **Physics**: 3D component → Ray Optics → Geometrical Optics. Air/vacuum
   background; no absorption (spot-pattern validation only).
2. **Geometry**: for each `mirror_k` row make a spherical cap: sphere
   radius = `roc_mm`, cap centre at (x, y, z), cap axis along (nx, ny, nz)
   (points from the mirror face toward the ring centre; the sphere centre
   sits at centre + ROC·n̂), clear radius = `aperture_r_mm`. Mirror 0
   additionally carries a concentric hole disk of `hole_r_mm` — model it
   as a postprocessing hit test (protocol §5.2) rather than a Boolean cut.
3. **Boundary conditions**: mirror caps = specular reflection; everything
   else absorbs. Store ray position at each boundary interaction.
4. **Release**: one chief ray from the `launch_ray` row (grid/bundle
   releases for the sensitivity stages). Sweep variables x_in, y_in
   (tangential/sagittal offsets at mirror 0), θ_t, θ_s.
5. **Sweeps**: (i) nominal; (ii) input sweeps to the capture envelopes in
   [capture_envelope.csv](capture_envelope.csv); (iii) per-DOF mirror
   perturbations from `comsol_perturbations.csv`; (iv) Monte-Carlo
   1000–5000 cases sampled uniformly inside the architecture envelope.
6. **Export**: chief-ray interaction points (x, y, z per bounce, ordered)
   to CSV → `compare_comsol.py --design <name> --csv <export>` reports
   RMS/worst deviation vs our tracer (pass < 10 µm, the same criterion the
   Optiland cross-validation met at 0.000 µm RMS).

## Native reference results (already run)

* Nominal: all 9 designs PASS with the expected pass count and OPL.
* Worst-case per-DOF (steps 7): **8 of 10 mirror-DOF extremes pass for
  every menu design**. The recurring failure is the coherent `d_ax` pair —
  all mirrors displaced radially by the same +max or −max, i.e. a uniform
  ring-radius change of 0.08 mm (flexure) / 0.18 mm (hybrid). That is the
  architecture's one soft axis: re-entrance accumulates ≈1.2 rad of
  transverse phase per mm of R_ring, so common-mode radial drift IS the
  thermal-breathing mode — already governed by the documented thermal
  windows (±26 K aluminium on the 20 m design) and the machined-trim law,
  and excluded from the random-drift budget by construction (a common-mode
  radial shift is a temperature signal, not a tolerance draw).
  Boundary designs (29 m ceiling, 14 cm compact) additionally fail the
  coherent `d_sag`+ (whole-ring vertical shift) at the hybrid envelope —
  consistent with their known walk-tightness.
* Per the protocol's own classification, a design failing a coherent
  worst case but passing Monte-Carlo is **marginal, requiring the drift
  source to be bounded** — for `d_ax` the bound is the thermal window,
  which the drone thermal budget already enforces.
* Monte-Carlo (step 8) at 5000 trials per design per architecture:
  [mc5000_drone_yield.csv](mc5000_drone_yield.csv) — run
  `drone_20m/mc5000.py`; yields and Wilson lower bounds vs the >99.9 %
  drone criterion, failure modes separated
  (incomplete / early-leak / exit-miss / overlap).

## Pass/fail thresholds (protocol §13, adopted)

* nominal pass count + exit direction: exact;
* no clipping of the beam bundle: `edge_clear_mm > 0`;
* pre-exit hole clearance: `hole_clear_mm > 0`;
* exit fully inside the hole: `exit_clear_mm ≥ 0`;
* MC yield: >99 % lab, >99.5 % field, **>99.9 % drone**.

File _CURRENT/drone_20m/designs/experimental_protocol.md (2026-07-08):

# Experimental verification protocol — measuring the paper's budgets

*(Executes the paper's second next step as a lab procedure: every
measurement has an expected value from the verified simulations and an
explicit pass band. Instruments assumed: the build-package bench, a
signal generator + lock-in (or DAQ with digital demod), calibrated gas
mixtures, a hot/cold chamber or lab HVAC authority of ±10 K, and a
shaker or the drone itself for the vibration step.)*

## P1 — Transmission vs photon budget

Method: power meter at collimator output (P₀) and at detector plane
(P₁), CH₄ laser, cell locked (build step 7). T_cell = P₁/P₀ ÷ chain
losses (window ×2 passes ≈ 0.99², collimator per datasheet).
**Expected:** T = R^(n−1): 83.9 % (flagship, n = 176) / 86.7 %
(standard, n = 144) at R = 0.999; the measured T yields the delivered
lot's R via R = T^(1/(n−1)) — record it; every other budget rescales
with it. **Pass:** within −5 % absolute of prediction with the fitted R
∈ [0.9975, 0.9995].

## P2 — Path-length verification

Method (either): (a) frequency-modulation phase delay — modulate the
laser at f_m = 5–20 MHz, measure RF phase between a reference detector
and the cell detector: Δφ = 2π f_m · OPL/c (25.72 m → 0.54° per MHz);
(b) ring-down-style time of flight with a fast pulse and >200 MHz
detector. **Expected:** 25.72 / 20.38 m. **Pass:** ±0.5 %.

## P3 — Fringe floor / noise-equivalent absorbance (the OD-noise claim)

Method: evacuated or N₂-flushed cell; sweep the laser over the working
window (≥1.5 cm⁻¹); record 30 min of spectra at 1 Hz; fit and remove a
3rd-order baseline per spectrum; compute (i) RMS residual absorbance at
1 s (NEA), (ii) Allan–Werle deviation of a fitted null concentration,
(iii) FFT of residuals in optical-frequency domain. **Expected:** NEA
class 2×10⁻⁵ (1σ, short-term) direct; ≤10⁻⁵ with WMS; Allan minimum
beyond 60 s. **Diagnostics designed in:** peaks in (iii) at
0.034–0.037 cm⁻¹ (flagship/standard chord FSR) indicate mirror-spot
scatter coupling — compare against the −34…−148 dB overlap budget;
1 cm⁻¹-scale ripple indicates window etalon (re-seat/tilt window);
0.4 cm⁻¹ ripple indicates collimator internal etalon. **Pass:** NEA ≤
1×10⁻⁴ direct at 1 s (paper's conservative LOD basis); target class
2×10⁻⁵.

## P4 — Polarization eigenaxis (paper §6.6)

Method: PM launch keyed sagittal; rotatable analyser + power meter on
the exit; measure transmitted power vs analyser angle at launch
polarization set 0° (sagittal) and 45°. **Expected:** sagittal launch →
extinction ratio ≥ 13 dB (purity ≥ 96.3–99.9 % depending on design);
45° launch → strongly elliptical output (ellipticity tens of degrees;
do not use). **Pass:** sagittal purity ≥ 95 %; record the full curve
for the paper's measured-vs-predicted figure.

## P5 — Thermal window and trim authority

Method: with the launch frozen, step ambient (or the ring heater) in
1 K increments; log transmission and exit-spot position. **Expected:**
transmission plateau over ±18 K (flagship) / ±26 K (standard) around
the lock point; ring-heater authority moves the closure peak by
1.7 µm/K equivalent. **Pass:** plateau ≥ ±10 K; peak recoverable by
heater across the full excursion.

## P6 — Vibration-to-signal (the "shaking" budget)

Method: mount the damped assembly on a shaker (or fly it); excite
60–700 Hz at 1.5–3 g RMS broadband; record transmission and retrieved
null concentration during excitation. **Expected:** transmission
modulation < a few %, dominated by launch-chain pointing; retrieved
concentration unaffected within the P3 noise (the flight-proven
precedent for this architecture class saw no effect on dampers).
**Pass:** no line-shaped artefacts; added white noise ≤ 2× quiescent;
any narrow spectral feature triggers a damper/lens iteration, not a
cell rebuild.

## P7 — Gas response (per channel)

CH₄: calibrated 2–100 ppm mixtures; expected sensitivity 3.8×10⁻⁵
absorbance per ppm·m → 129 ppb (1σ) at NEA 10⁻⁴, 20.4 m. NH₃ 1512.2 nm:
92 ppb basis; note wall adsorption — use PTFE lines, log step-response
time. H₂ 2121.8 nm: %-level mixtures in N₂; expected 0.17–0.31 %v at
NEA 10⁻⁴ (direct); fit with a Rautian/Galatry profile (the line is
Dicke-narrowed, FWHM ≈ 0.026–0.04 cm⁻¹ at 1 atm — a Voigt fit will bias
low); WMS target: tens of ppm. **Pass:** linearity R² ≥ 0.999 over one
decade; retrieved LODs within 2× of the basis values.

## P8 — Contamination self-monitor (open-flow mode)

Method: log P1's fitted R continuously during dusty/field operation.
**Expected:** ΔR per mirror of 10⁻⁴ reads as ≈2 % transmission change
at 204 chords — the cell is its own reflectometer. **Action level:** R
drop >5×10⁻⁴ → inspect/purge; heater a few K above dew point in humid
air.

Deliverables per cell: filled P1–P8 record, fitted lot R, measured NEA
+ Allan plot, polarization curve, thermal plateau — these are the
measured panels the paper's revision needs to move from
simulation-verified to demonstrated.

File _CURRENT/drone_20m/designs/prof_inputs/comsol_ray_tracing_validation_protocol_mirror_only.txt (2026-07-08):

=== comsol_ray_tracing_validation_protocol_mirror_only.docx | inline images: 8 ===

COMSOL Ray-Tracing Validation Protocol for Mirror-Only Multipass Gas-Cell Spot-Pattern Designs
Protocol based on the integrated construction, alignment, and operational drift tolerance framework
Prepared for laboratory, field, and drone configurations; mirror-only optical validation without modelling the full gas-cell body
[Heading 1] Abstract
This document gives a practical validation protocol for using COMSOL Multiphysics with the Ray Optics Module to validate Herriott or multipass gas-cell beam spot patterns using only the two concave mirrors and their apertures. The protocol intentionally avoids a full gas-cell body model at the first stage. Instead, the mechanical effects of aluminium, stainless steel, titanium, Invar, Bosch-rail aluminium, 3D-printed plastic, CNC-milled engineering plastics, injection-moulded plastic, and hybrid plastic-metal designs are introduced as six-degree-of-freedom mirror perturbation vectors. This makes it possible to screen optical designs quickly and then decide which designs deserve full mechanical FEA or prototype testing.
Index Terms - COMSOL, Ray Optics Module, Herriott cell, multipass gas cell, mirror-only validation, spot pattern, drone sensor, field sensor, construction tolerance, operational drift, plastic mirror mount, aluminium mirror mount.
[Heading 1] 1. Purpose and Scope
The objective is to validate whether a proposed beam spot pattern remains feasible when mirror construction errors are aligned out and when the remaining assembly is subjected to realistic thermal, vibration, pressure, and cycling drift. The first COMSOL model should contain only the mirror pair, the input/output holes or aperture masks, and the ray release. The gas-cell tube, flanges, seals, and full mirror mount body are not modelled as solid mechanics in this stage.
This mirror-only method is useful because the ray-tracing question can be separated from the structural question. COMSOL validates whether a nominal and perturbed spot pattern clears the mirror apertures and output hole. The integrated tolerance framework supplies the perturbation vectors that represent different material and mounting choices.
The output of the protocol is a validated design window: maximum allowed input spot position, maximum allowed input angle, maximum allowed mirror position drift, maximum allowed mirror angular drift, minimum clearance from mirror hole, and pass/fail status for lab, field, and drone environments.
Fig. 1. Mirror-only validation workflow. Construction tolerance is used as an alignment capture-range check; final in-use tolerance comes from residual alignment plus operational drift.
Fig. 2. Mirror-only COMSOL model. Only M1, M2, input/output aperture masks, and ray releases are required for first-stage optical validation.
Fig. 3. Six-degree-of-freedom perturbation convention used for construction, alignment residuals, and operational drift.
[Heading 1] 2. Definitions and Coordinate System
--- TABLE ---
Term | Meaning in this protocol
Construction tolerance | Manufacturing and fixing accuracy of mirror, hole, seat, dowel, O-ring groove, adhesive dots, and mount references. It is recoverable if the alignment system has enough capture range.
Alignment tolerance | Residual error left after practical alignment. It depends on component resolution, ease of alignment, number of adjustment knobs, access, visibility of the pattern, and user capability.
Operational drift | Post-alignment motion caused by thermal expansion, vibration, pressure deformation, screw relaxation, adhesive creep, O-ring relaxation, and repeated thermal/vibration cycling.
Position drift Pxy | Independent equivalent input spot-position movement in the x-y plane.
Theta_xy | Independent equivalent input-angle drift caused by alignment residual and operational effects. It is not the same as spot-position drift.
Combined spot-pattern variation | For mirror clearance only, position drift and angle-induced drift are combined as Pxy + L*Theta_xy. At L = 300 mm and theta in mrad, the angle-induced spot shift is 0.3*Theta_xy mm.
--- END TABLE ---
Table I. Definitions used throughout the mirror-only validation protocol.
The coordinate convention is x = horizontal transverse displacement, y = vertical transverse displacement, z = axial mirror-spacing direction, dtheta_x = pitch, dtheta_y = yaw, and dtheta_z = roll. All translations are in mm and all angular terms are in mrad unless stated otherwise.
[Heading 1] 3. Physical Constants and Material Properties Used for Perturbation Estimates
The material constants are typical design values used to define perturbation envelopes. They should be replaced by supplier-specific data for final engineering release. The key point is that the Ray Optics model does not need to contain the full material body. The material effect is introduced as a displacement/tilt perturbation of the mirror boundaries.
--- TABLE ---
Material / part | CTE (ppm/K) | Young modulus (GPa) | Density (kg/m3) | Use in validation | Ref.
Fused silica mirror | 0.50-0.60 | 72 | 2200 | Reference mirror substrate; low CTE. | [6]
Aluminium 6061/6082 | 23-24 | 69 | 2700 | Low mass and low cost; suitable for lab/field/drone when flexure isolated. | [5]
Bosch-type aluminium extrusion | 23-24 | ~69 | ~2700 | CTE similar to aluminium, but joint slip dominates optical drift. | [5]
Stainless steel 304/316 | 16-17 | 190-200 | 7900-8000 | Good ruggedness and screw stability; heavy. | [5]
Titanium Ti-6Al-4V | 8.5-9.0 | 110-115 | 4430 | Best drift-to-weight metal candidate. | [5]
Invar 36 | 1.2-1.6 | 140-150 | 8050 | Lowest thermal mismatch but heavy. | [5]
PEEK, CNC machined | 45-50 | 3.5-4.0 | 1300-1320 | Best engineering plastic for low creep and high temperature margin. | [7]
POM/Delrin, CNC machined | 90-110 | 2.8-3.2 | 1400-1420 | Very machinable and low cost; high CTE compared with metals. | [8]
PEI/Ultem, printed or machined | 55-60 | 3.0-3.5 | 1270 | Better high-temperature plastic than PA12/Delrin; printable grades available. | [9]
PA12, 3D printed | 100-160 | 1.3-1.8 | 1000-1030 | Very low cost and mass; anisotropy and creep risk. | [10]
EPO-TEK 353ND epoxy | 54 below Tg; 206 above Tg | ~2-4 | ~1200 | Use as three small dots, not a full ring. | [4]
FKM/silicone O-ring | ~150-250 | low | 1200-1900 | Use only for sealing; do not use as mirror reference. | [11]
--- END TABLE ---
Table II. Typical material properties used to assign thermal and mechanical perturbation envelopes.
[Heading 1] 4. Theoretical Framework
A reflected ray is twice as sensitive to mirror tilt as to input ray angle. Therefore, a mirror angular perturbation dtheta_m produces approximately 2L*dtheta_m displacement at the opposite mirror. An input angular perturbation dtheta_in produces L*dtheta_in displacement at the opposite mirror.
For the validation model, it is useful to keep input spot position and input angle separate. Position drift changes where the pattern is placed on the mirror. Angular drift changes how the pattern walks across subsequent reflections. They only become one scalar when checking physical clearance between spot pattern and mirror apertures.
For L = 300 mm and theta expressed in mrad, the angle-induced shift at the next mirror is approximately 0.3*theta for input-angle equivalent drift and 0.6*theta_m for actual mirror tilt. The protocol reports equivalent input angle, so the 0.3 factor is used for clearance calculations.
v = [dx, dy, dz, dtheta_x, dtheta_y, dtheta_z]
Pxy = sqrt(dx_total^2 + dy_total^2)
Theta_xy = sqrt(dtheta_x,total^2 + dtheta_y,total^2)
Angle-induced spot movement = L * Theta_xy = 0.3 * Theta_xy mm for L = 300 mm and Theta in mrad
Combined clearance variation = Pxy + 0.3 * Theta_xy
Thermal translation estimate: dx_th ≈ k_pos * L_ref * |alpha_mount - alpha_mirror| * ΔT
Thermal angular estimate: dtheta_th ≈ k_asym * |alpha_mount - alpha_mirror| * ΔT
Monte Carlo vector: v_total = v_align_residual + v_thermal + v_vibration + v_pressure + v_cycle
[Heading 1] 5. COMSOL Mirror-Only Model Setup
[Heading 2] 5.1 Model type and physics
Create a 3D Component and add the Ray Optics Module, Geometrical Optics interface. COMSOL describes the Ray Optics Module as a ray-tracing approach for optically large systems in which rays can reflect, refract, or be absorbed [1], [2].
Use air or vacuum as the homogeneous background medium. Gas absorption is not needed for spot-pattern validation. Absorption can be added later only after the mechanical/optical pattern is validated.
Use deterministic ray release for nominal design and grid/random ray bundle releases for sensitivity testing.
[Heading 2] 5.2 Mirror geometry without cell body
Create M1 and M2 as spherical or paraboloidal reflective surfaces. The simplest implementation is two spherical-cap surfaces with radius of curvature R = 2f, clear diameter D, and separation L.
Add input and output aperture/hole masks as circular exclusion regions on the mirror surfaces. If Boolean holes are difficult in the surface geometry, implement them as postprocessing tests: any ray hit within the hole disk is counted as hole interaction/exit, and any ray hit outside clear aperture is counted as clipping.
Do not model the gas-cell tube, walls, flanges, or external brackets at this stage. Their mechanical effect is introduced using mirror perturbations.
[Heading 2] 5.3 Ray release
Release a ray bundle from the input hole or from an upstream collimator plane. For spot-pattern validation, use a chief ray plus a circular ray bundle representing the beam diameter.
Define input variables x_in, y_in, z_in, theta_x,in, theta_y,in, and optionally beam radius w. These become sweep parameters.
For a collimated input beam, the primary variables are x_in, y_in, theta_x,in and theta_y,in. z_in mainly changes phase/path offset and is less critical for geometric spot placement unless a focusing input is used.
[Heading 2] 5.4 Boundary conditions
Set mirror surfaces as specular reflecting boundaries. Set non-mirror aperture stop surfaces as absorbing or disappearing boundaries.
If mirror holes are explicit geometry, rays passing through the hole can be recorded as output rays. If mirror holes are not explicit geometry, define hit-test expressions for distance from the hole centre and use them for classification.
Use stored ray positions at every boundary interaction to generate spot coordinates and pass count.
[Heading 1] 6. Validation Protocol
Step 1 - Define the candidate spot pattern: Specify D, R, L, input-hole radius, output-hole radius, hole offset, input chief-ray position/angle, beam diameter, target number of passes, and minimum clearance margin. Use sparse patterns for drone designs and denser patterns only for lab designs with accessible realignment.
Step 2 - Run the nominal mirror-only model: Trace the chief ray and the full beam bundle. Record every intersection on M1 and M2. Confirm the intended number of spots, no clipping, and exit through the correct aperture/hole.
Step 3 - Extract nominal metrics: Export spot coordinates, nearest-neighbour spot spacing, distance to mirror edge, distance to mirror hole, number of passes, total geometric path length, output position, output angle, and beam footprint size.
Step 4 - Apply construction capture-range checks: Use construction vectors from the tolerance framework only to check whether the kinematic/flexure/bonding method can recover the nominal pattern. Do not add construction tolerance directly to final in-use drift if the system is alignable.
Step 5 - Apply alignment residual vectors: Choose Easy, Medium, or Hard alignment residuals. Apply residual dx, dy, dz, dtheta_x, dtheta_y and dtheta_z to M1, M2, or the input ray and rerun the spot pattern.
Step 6 - Apply operational perturbation vectors: For each material/mount/environment combination, apply thermal, vibration, pressure and cycling perturbations. These are implemented as parametric changes in mirror position and angle.
Step 7 - Run worst-case sweeps: Run positive and negative perturbation extremes for each degree of freedom independently. Then run combined worst-case vectors for lab, field and drone cases.
Step 8 - Run Monte Carlo tolerance simulation: Sample v_total from uniform or normal distributions bounded by the maximum drift table. Use at least 250 rays for a quick design screen and 1000-5000 cases for final validation.
Step 9 - Classify pass/fail: Pass if all rays clear the mirror edge, avoid unintended hole clipping, preserve required number of passes, stay within output collection area, and maintain minimum spot spacing and hole clearance after worst-case and Monte Carlo tests.
Step 10 - Select design for next stage: Only designs passing mirror-only validation should proceed to full mechanical FEA, detailed mount design, thermal cycling test, and physical vibration testing.
[Heading 1] 7. Alignment Regimes to Use in COMSOL Sweeps
--- TABLE ---
Regime | dx (mm) | dy (mm) | dz (mm) | dtheta_x (mrad) | dtheta_y (mrad) | dtheta_z (mrad) | When to use
Easy | 0.02 | 0.02 | 0.03 | 0.05 | 0.05 | 0.10 | Polaris/flexure mount, visible spot pattern, accessible knobs, trained user.
Medium | 0.05 | 0.05 | 0.07 | 0.15 | 0.15 | 0.25 | Lockable cartridge or fixed collimator plate, moderate access, field-trained user.
Hard | 0.12 | 0.12 | 0.18 | 0.40 | 0.40 | 0.60 | Miniature drone package, blind or partly hidden alignment, plastic or bonded mounts, limited adjustability.
--- END TABLE ---
Table III. Practical alignment residual vectors to use as input perturbations in COMSOL.
[Heading 1] 8. Operational Perturbation Envelopes by Environment and Material/Mount Choice
The following table is the key input for the COMSOL perturbation sweeps. It gives maximum post-alignment operational drift vectors for each environment and design choice. Plastic and hybrid options are included directly, not as a separate section. Values are based on the integrated tolerance model: material CTE mismatch, stiffness, mass, mount compliance, adhesive/O-ring creep, vibration susceptibility, pressure/cycling sensitivity, and practical alignment accessibility.
[Heading 2] 8.1 Lab perturbation table
--- TABLE ---
Configuration | Ease | dx | dy | dz | dθx | dθy | dθz | Pxy | Theta_xy | Combined spot
Al isostatic flexure mirror mount | Easy | 0.020 | 0.020 | 0.030 | 0.050 | 0.050 | 0.100 | 0.028 | 0.071 | 0.049
Al monolithic pocket | Medium | 0.050 | 0.050 | 0.060 | 0.120 | 0.120 | 0.200 | 0.071 | 0.170 | 0.122
Stainless lockable cartridge | Easy | 0.025 | 0.025 | 0.040 | 0.080 | 0.080 | 0.150 | 0.035 | 0.113 | 0.069
Titanium flexure cartridge | Easy | 0.020 | 0.020 | 0.030 | 0.050 | 0.050 | 0.100 | 0.028 | 0.071 | 0.049
Invar mirror insert | Easy | 0.018 | 0.018 | 0.025 | 0.040 | 0.040 | 0.080 | 0.025 | 0.057 | 0.042
Bosch rail aluminium reference | Medium-Hard | 0.100 | 0.100 | 0.150 | 0.300 | 0.300 | 0.500 | 0.141 | 0.424 | 0.269
3D-printed PA12/PLA/ABS mount | Hard | 0.200 | 0.200 | 0.300 | 0.700 | 0.700 | 1.000 | 0.283 | 0.990 | 0.580
CNC-milled PEEK/Delrin/Ultem | Medium | 0.100 | 0.100 | 0.150 | 0.300 | 0.300 | 0.500 | 0.141 | 0.424 | 0.269
Injection-moulded plastic + inserts | Medium | 0.080 | 0.080 | 0.120 | 0.250 | 0.250 | 0.400 | 0.113 | 0.354 | 0.219
Hybrid plastic body + Al cartridge | Medium | 0.050 | 0.050 | 0.070 | 0.150 | 0.150 | 0.250 | 0.071 | 0.212 | 0.134
--- END TABLE ---
Table IV. Lab maximum post-alignment operational perturbation vectors. Units: mm for dx,dy,dz and mrad for dtheta terms. Combined spot is in mm at L=300 mm.
Fig. 4. Lab combined spot-pattern variation for mirror-only COMSOL validation.
[Heading 2] 8.2 Field perturbation table
--- TABLE ---
Configuration | Ease | dx | dy | dz | dθx | dθy | dθz | Pxy | Theta_xy | Combined spot
Al isostatic flexure mirror mount | Easy | 0.050 | 0.050 | 0.080 | 0.150 | 0.150 | 0.200 | 0.071 | 0.212 | 0.134
Al monolithic pocket | Medium | 0.100 | 0.100 | 0.120 | 0.300 | 0.300 | 0.400 | 0.141 | 0.424 | 0.269
Stainless lockable cartridge | Medium | 0.060 | 0.060 | 0.090 | 0.200 | 0.200 | 0.250 | 0.085 | 0.283 | 0.170
Titanium flexure cartridge | Easy | 0.050 | 0.050 | 0.080 | 0.150 | 0.150 | 0.200 | 0.071 | 0.212 | 0.134
Invar mirror insert | Easy | 0.040 | 0.040 | 0.060 | 0.120 | 0.120 | 0.150 | 0.057 | 0.170 | 0.107
Bosch rail aluminium reference | Hard | 0.300 | 0.300 | 0.500 | 1.000 | 1.000 | 1.500 | 0.424 | 1.414 | 0.849
3D-printed PA12/PLA/ABS mount | Hard | 0.500 | 0.500 | 0.700 | 2.000 | 2.000 | 2.500 | 0.707 | 2.828 | 1.556
CNC-milled PEEK/Delrin/Ultem | Medium-Hard | 0.250 | 0.250 | 0.350 | 0.900 | 0.900 | 1.200 | 0.354 | 1.273 | 0.735
Injection-moulded plastic + inserts | Medium-Hard | 0.220 | 0.220 | 0.300 | 0.800 | 0.800 | 1.000 | 0.311 | 1.131 | 0.651
Hybrid plastic body + Al cartridge | Medium | 0.100 | 0.100 | 0.140 | 0.300 | 0.300 | 0.400 | 0.141 | 0.424 | 0.269
--- END TABLE ---
Table V. Field maximum post-alignment operational perturbation vectors. Units: mm for dx,dy,dz and mrad for dtheta terms. Combined spot is in mm at L=300 mm.
Fig. 5. Field combined spot-pattern variation for mirror-only COMSOL validation.
[Heading 2] 8.3 Drone perturbation table
--- TABLE ---
Configuration | Ease | dx | dy | dz | dθx | dθy | dθz | Pxy | Theta_xy | Combined spot
Al isostatic flexure mirror mount | Easy | 0.050 | 0.050 | 0.080 | 0.150 | 0.150 | 0.200 | 0.071 | 0.212 | 0.134
Al monolithic pocket | Medium | 0.100 | 0.100 | 0.100 | 0.300 | 0.300 | 0.400 | 0.141 | 0.424 | 0.269
Stainless lockable cartridge | Medium | 0.080 | 0.080 | 0.100 | 0.250 | 0.250 | 0.300 | 0.113 | 0.354 | 0.219
Titanium flexure cartridge | Easy | 0.045 | 0.045 | 0.070 | 0.130 | 0.130 | 0.180 | 0.064 | 0.184 | 0.119
Invar mirror insert | Medium | 0.040 | 0.040 | 0.060 | 0.100 | 0.100 | 0.150 | 0.057 | 0.141 | 0.099
Bosch rail aluminium reference | Hard | 0.500 | 0.500 | 0.800 | 2.000 | 2.000 | 3.000 | 0.707 | 2.828 | 1.556
3D-printed PA12/PLA/ABS mount | Hard | 0.700 | 0.700 | 0.900 | 3.000 | 3.000 | 3.500 | 0.990 | 4.243 | 2.263
CNC-milled PEEK/Delrin/Ultem | Hard | 0.300 | 0.300 | 0.400 | 1.200 | 1.200 | 1.500 | 0.424 | 1.697 | 0.933
Injection-moulded plastic + inserts | Medium-Hard | 0.250 | 0.250 | 0.350 | 1.000 | 1.000 | 1.200 | 0.354 | 1.414 | 0.778
Hybrid plastic body + Al cartridge | Medium | 0.120 | 0.120 | 0.180 | 0.400 | 0.400 | 0.600 | 0.170 | 0.566 | 0.339
--- END TABLE ---
Table VI. Drone maximum post-alignment operational perturbation vectors. Units: mm for dx,dy,dz and mrad for dtheta terms. Combined spot is in mm at L=300 mm.
Fig. 6. Drone combined spot-pattern variation for mirror-only COMSOL validation.
[Heading 1] 9. Material and Cost Selection Logic
For laboratory validation, aluminium or stainless external/flexure mounts are preferred because construction errors are easily aligned out and vibration is low. Plastic is acceptable for proof-of-concept ray-pattern work but should not define the final mirror reference unless the pattern has a large clearance margin.
For field validation, aluminium flexure, stainless cartridge, titanium cartridge, or hybrid plastic body with aluminium mirror cartridge are the practical candidates. Bosch rail and all-plastic references should be treated as risk cases and validated only for sparse patterns.
For drone validation, the recommended low-risk design is an aluminium isostatic flexure or titanium flexure. The recommended low-cost design is a hybrid plastic body with aluminium mirror cartridge. Injection-moulded plastic with metal inserts is possible for volume production, but COMSOL validation must include the larger drift vector and thermal-cycle/creep margin.
Fig. 7. Drone cost-versus-drift trade-off. Lower-cost plastic options generally need larger spot-pattern clearance and more conservative drift validation.
Fig. 8. Conceptual mirror mount options: aluminium flexure, aluminium pocket, 3D-printed plastic, CNC-milled engineering plastic, and injection-moulded plastic with inserts.
[Heading 1] 10. Detailed COMSOL Implementation Checklist
[Heading 2] Global parameters
Define L, R, D, hole radius, hole offset, beam radius, wavelength label, x_in, y_in, theta_x, theta_y, and perturbation variables for M1 and M2.
Use units explicitly: mm for geometry, rad or mrad for rotations. Avoid hidden unit conversion errors.
[Heading 2] Geometry
Create mirror surfaces as spherical caps or equivalent reflective surfaces.
Create or postprocess mirror clear aperture and hole masks.
Use work planes at each mirror if postprocessing hole distance is easier than explicit Boolean holes.
[Heading 2] Physics settings
Use Geometrical Optics / Ray Optics.
Set mirror boundaries to specular reflection.
Set aperture stops and outside-clear-aperture surfaces to absorb/disappear.
Store ray position and direction at boundary interactions.
[Heading 2] Parametric studies
Nominal input sweep: x_in, y_in, theta_x, theta_y.
Mirror perturbation sweep: dx_M1, dy_M1, dz_M1, dtheta_M1x, dtheta_M1y, dtheta_M1z, and same for M2.
Material/environment sweep: select the row from the perturbation table and apply the matching vector.
[Heading 2] Postprocessing
Generate spot scatter plot separately for M1 and M2.
Calculate minimum distance to mirror edge and hole edge.
Calculate nearest-neighbour spot distance.
Calculate pass count and total path length.
Classify each run as pass, marginal, or fail.
[Heading 1] 11. Validation Protocol by Destination
[Heading 2] Laboratory design
Use large mirror aperture and accessible kinematic alignment.
Validate dense spot patterns and longer path lengths because realignment is possible.
Acceptance target: combined spot-pattern variation should preferably remain below 0.2-0.3 mm after residual alignment and lab drift.
Plastic prototypes may be used for early geometry evaluation, but final optical references should be aluminium/stainless/titanium/Invar if high reproducibility is needed.
[Heading 2] Field design
Use lockable cartridge or flexure references.
Validate transport vibration and thermal swings.
Acceptance target: combined spot-pattern variation should preferably remain below 0.3-0.5 mm, depending on hole clearance and beam diameter.
Hybrid plastic body + aluminium mirror cartridge is a strong low-cost field option.
[Heading 2] Drone design
Use sparse spot patterns with larger clearance margins.
Validate the maximum thermal and vibration vector for each material choice.
Acceptance target: combined spot-pattern variation should preferably remain below 0.1-0.2 mm for dense/small-hole designs, or below the explicitly available clearance for a larger-aperture/sparse drone design.
Avoid Bosch rail and pure 3D-printed plastic as final optical references. Use aluminium flexure, titanium flexure, aluminium pocket, or hybrid plastic body + aluminium mirror cartridge.
[Heading 1] 12. Data Recording Template
--- TABLE ---
Run ID | Environment | Design | L | R | Input x/y | Input theta x/y | Perturbation vector | Pass count | Path length | Minimum edge clearance | Minimum hole clearance | Output x/y/theta | Result
D-AL-FLX-001 | Drone | Al flexure | 300 mm | 400 mm | 0.0, 0.0 mm | 3.2, 0.4 mrad | Table VI row 1 | 104 | 31.2 m | >0.6 mm | >0.3 mm | within detector | Pass
--- END TABLE ---
Table VII. Suggested COMSOL run log template. Export one row per parametric or Monte Carlo case.
[Heading 1] 13. Pass/Fail Criteria
Nominal pattern must produce the required number of passes and expected output ray direction.
No ray in the beam bundle may clip the mirror edge or unintended hole region.
Minimum distance from any spot footprint to the hole edge must exceed the combined spot-pattern variation plus beam radius plus safety margin.
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

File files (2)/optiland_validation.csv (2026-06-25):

Bounce_Number | Mirror_ID | Custom_X_m | Custom_Y_m | Custom_Z_m | Optiland_X_m | Optiland_Y_m | Optiland_Z_m | Error_X_um | Error_Y_um | Error_Z_um | Error_Magnitude_um | Optiland_AOI_deg
1 | 1 | 0.035355339 | 0.035355339 | -0.019848485 | 0.035355339 | 0.035355339 | -0.019848485 | 0.000 | -0.000 | 0.000 | 0.000 | 67.5002
2 | 2 | 0.000000000 | 0.050000000 | -0.019696970 | 0.000000000 | 0.050000000 | -0.019696970 | 0.000 | 0.000 | 0.000 | 0.000 | 67.5002
3 | 3 | -0.035355339 | 0.035355339 | -0.019545455 | -0.035355339 | 0.035355339 | -0.019545455 | 0.000 | 0.000 | 0.000 | 0.000 | 67.5002
4 | 4 | -0.050000000 | 0.000000000 | -0.019393939 | -0.050000000 | 0.000000000 | -0.019393939 | 0.000 | 0.000 | 0.000 | 0.000 | 67.5002
5 | 5 | -0.035355339 | -0.035355339 | -0.019242424 | -0.035355339 | -0.035355339 | -0.019242424 | 0.000 | 0.000 | 0.000 | 0.000 | 67.5002
6 | 6 | -0.000000000 | -0.050000000 | -0.019090909 | -0.000000000 | -0.050000000 | -0.019090909 | -0.000 | 0.000 | 0.000 | 0.000 | 67.5002
7 | 7 | 0.035355339 | -0.035355339 | -0.018939394 | 0.035355339 | -0.035355339 | -0.018939394 | -0.000 | -0.000 | 0.000 | 0.000 | 67.5002
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

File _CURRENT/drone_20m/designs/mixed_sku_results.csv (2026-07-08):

N | s | roc_a | roc_b | r_ring | k | n_exit | res_t | res_s | opl_est | ang_t | ang_s | off_z | w0 | waist_frac | exit_miss | sku_a | sku_b | feasible | reason | opl_m | hole_clear | sep_margin | w_max | envelope_mm | throughput
12 | 5 | 100.0 | 150.0 | 48.3065740668104 | 33 | 396 | 0.013811949285697622 | 0.05095153626767335 | 37.26532564934415 | 0.020224294371871787 | 0.020229699469367986 | 5.532110719180073e-05 | 0.3468790443665958 | 0.550810547372231 | 2.970408792554486 | CM254-050-M01 | CM254-075-M01 | False | no closure (miss 2.97)
12 | 5 | 100.0 | 150.0 | 48.55697040934318 | 31 | 372 | 0.013275635233396699 | 0.0051153624141111464 | 34.88896265891499 | 0.019195176011504077 | 0.023084789384239912 | 0.00020889328130731867 | 0.26437985276402676 | 0.5932224556095712 | 1.9679523039363776e-05 | CM254-050-M01 | CM254-075-M01 | False | miss=0.000 clear=0.57 sep=-1.78 env=133 | 34.874903047385914 | 0.5703178080291749 | -1.7781251877628457 | 1.040455063310748 | 133.11394081868636 | 0.6899158648955463
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

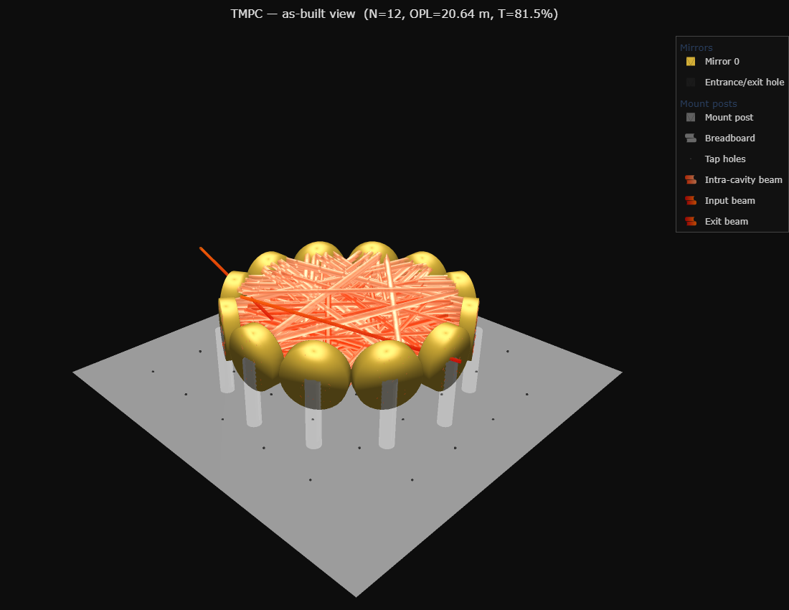
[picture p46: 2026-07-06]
_CURRENT/drone_20m/designs/figures/drone_14cm_experiment.png

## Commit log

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2026-06-25 Log input_offset_z and input_angle in SimResult dict
    These are sampled by Sobol during dataset generation and used in the
    simulation, but were missing from the output CSV — preventing any
    post-hoc reproduction of long-OPL designs that depend on the helical
    input offset to avoid retracing.
2026-06-25 Add per-mirror spot constellation plots
    For each preset also emit <name>_mirrors.html showing where every visit
    to each mirror landed in its local (tangential, sagittal) plane, with
    the aperture circle for reference. Reveals that the current chord-skip
    model produces collinear vertical streaks rather than the elliptic /
    Lissajous patterns of a continuous Herriott cell — useful for spotting
    when the model's combinatorial assumption is too restrictive.
2026-06-25 Add ABCD-Lissajous spot model alongside raytrace constellations
    For each preset also emit <name>_mirrors_abcd.html that propagates the
    paraxial (position, slope) state through the per-bounce ray-transfer
    matrix M = [[1,c],[-2/R, 1-2c/R]] in both tangential and sagittal axes.
    Revisits to the same mirror now trace an ellipse (R_t = R_s) or a
    Lissajous figure (R_t != R_s) -- the classical Herriott pattern --
    instead of the vertical streak the combinatorial raytrace produces.
    Adds a toroidal_lissajous preset (R_t=500 mm, R_s=300 mm) so the
    two-frequency Lissajous case is visible out of the box.
2026-06-30 Fix validate: model mirror curvature in Optiland cross-check
    The Optiland cross-validation used flat mirrors (radius=inf) while the v5
    simulator uses curved mirrors, so it only matched chord_skip=1 centre-hit
    patterns and reported a false FAIL for any curved-mirror design with off-centre
    spots (e.g. bo_best_one_inch, chord_skip=7: 234 mm "error"). It also compared
    Optiland's AOI against the chord_skip=1 polygon formula instead of the actual
    ray-tracer.
    Fixes:
    - Model the mirror ROC in Optiland (radius=R_t); reproduces the v5 curved
    tracer to ~0 um for spherical cells.
    - Compare Optiland AOI/chord/positions against the v5 ray-tracer (the thing
    being cross-validated), not the chord_skip=1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
2026-07-01 Fix hole-truncation hard fail when beam diameter equals hole diameter
    compute_losses returned truncation loss = 1.0 (zero throughput) when the
    input beam exactly fills the entrance hole. At equality the Gaussian
    clipping formula already gives the physical answer (e^-2 = 13.5% loss),
    so only strictly larger beams should hard-fail.
2026-07-01 Add drone 20 m design-search harness (analytic prescreen + traced checks)
    Stage A enumerates Thorlabs CM127/CM254 catalog ROCs x N x chord_skip x
    R_ring against packing, envelope (<190 mm), per-plane astigmatic
    stability and hole re-entrance phase closure. Stage B verifies survivors
    with the exact v5 ray tracer -- exit through the 1.3 mm entrance hole,
    hole clearance of intermediate spots, beam-edge aperture margin, spot
    overlap, stability -- and polishes (R_ring, launch offset, launch angle)
    with Nelder-Mead against the catalog-locked ROC.
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2026-07-02 Search v3: closure modes, odd-k parity rule, continuous objective, 5-DOF refine
    - Tangential zero-crossing launch closes at phase 0 OR pi; sagittal
    offered as cos-mode (height offset) or sin-mode (vertical tilt):
    4x more catalog re-entrance coincidences.
    - Odd spots-per-mirror only, with gcd(M,k)=1 in both planes: evenly
    spaced constellations, no intermediate spot on the hole.
    - Objective evaluates margins at the designed exit bounce so the
    optimiser landscape is continuous across the hole-capture threshold
    (it previously walled at EXIT_TOL with 0.5000 mm misses).
    - Refine = 0.02 mm R_ring scan (valley is ~0.02 mm wide at ~1 rad/mm
    accumulated phase) + Nelder-Mead over (R_ring, o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
2026-07-02 Search v4: size-class driver, N 8-16, 2-D aperture rule, asymmetric seeds
    - Multi-class driver: verified designs per envelope class (110/120/140/
    160/190 mm) with class-scaled OPL floors -- exposes the size vs OPL vs
    throughput trade as a menu instead of one point.
    - N restricted to 8..16 and one-inch CM254 only (user constraints).
    - Aperture-fit prescreen now uses the 2-D Lissajous extent (~1.3x the
    per-plane amplitude); the 1-D rule let k=13-15 constellations through
    that could never fit, which is why spot overlap was the last failing
    check across the previous run.
    - Seeds include asymmetric per-plane amplitude ratios to spread the
    worst-pair spot distance; separation weighted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
2026-07-02 Search v6: exact all-mirror constellations + mode-matched injection -- first feasible 20 m design
    Two decisive physics fixes:
    - Constellation model now evaluates ALL N mirrors of the closed n-bounce
    Lissajous (each mirror carries the same k-point pattern at a different
    phase origin; checking only mirror 0 hid the worst pair, which is why
    spots overlap survived every earlier prescreen). Signed per-plane
    phase residuals gate which candidates the single R_ring knob can
    actually close.
    - Mode-matched launch: the 1.3 mm collimated input is focused so the
    cell rides its own eigenmode (waist ~0.33 mm near mid-chord, free
    waist size/position DOFs, hard w(hole) <= 1.3 mm check). Beam st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
2026-07-02 Add drone_20m/drone_25m/drone_16cm presets + tracked design deliverables
    - Three verified headline designs as first-class presets (the platform
    CLI reproduces 20.35 m / 144 bounces / 11.3% for drone_20m exactly).
    - cli.py: presets now own their n_passes (was silently reset to 8*N).
    - drone_20m/designs/: as-built specs, design JSONs, verified-designs
    CSV -- deliverables tracked in git (results/ stays ignored).
    [analytic_candidates.csv, verified_designs.csv]
2026-07-02 Add drone design-suite README + tracked verification figures
    Menu of 7 verified designs (13.6-24.8 m, 141-180 mm), the physics that
    made them work (chord-skip chords, ring-radius closure tuning, exact
    all-mirror constellation number theory, mode-matched injection),
    tolerance MC summary, literature positioning, and reproduce commands.
    [budget.csv, mc_summary.csv, sensitivity.csv]
2026-07-02 Feature drone designs in repo README; add per-design tolerance figures
    Also: investigations harness (ROC compensation / thermal window / M2
    robustness), M2 override in the evaluator, --r-step and --classes args
    for targeted sub-140 mm enrichment, k=15 patterns for N<=13.
    [mc_summary_drone_16cm.csv, mc_summary_drone_25m.csv]
2026-07-02 Engineering studies: ROC compensation, thermal windows, M2 robustness
    - ROC +/-1% (full Thorlabs band) absorbed by a linear ring trim
    (0.72 mm/% Ø180 designs, 0.62 mm/% drone_16cm), full check matrix
    restored -- codified as the assembly procedure.
    - Thermal windows with frozen launch: drone_20m +/-26 K on plain
    aluminium (invar >= +/-30 K everywhere); drone_16cm wants +/-8 K.
    - All designs pass every physical check up to M2 = 1.3.
    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
    [study_m2.csv, study_roc_compensation.csv, study_thermal.csv]
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2026-07-02 Add research-grade draft paper (docx + pdf + generator script)
    11-page journal-style draft presenting the verified design suite:
    abstract, literature-grounded introduction, theory (chord-skip
    geometry, dual-plane closure, constellation rule, mode-matched
    coupling), methods with Optiland cross-validation, verified menu +
    headline design, Monte-Carlo tolerances, ROC/thermal/M2 compensation,
    literature-comparison discussion, 6 embedded figures, 4 tables,
    15 references. Author list + a few citations flagged for the user to
    confirm; regenerates via paper/build_paper.js.
2026-07-02 Paper v2: prof-review draft -- R=0.999, drone mass budget, tightened
    - Reflectivity 0.999 primary (86.7% for the headline design) with
    coating sensitivity kept in brackets; long-path corner now clearly
    dominant.
    - New drone-integration section with a CAD-level mass budget
    (~1.0-1.2 kg payload incl. laser electronics).
    - Prior exploration woven in as motivation (N=9/skip=4 +67% OPL
    discovery, half-inch 12 m catalogue ceiling).
    - Removed journal boilerplate (keywords, note page, sensitivity
    figure), compressed methods/discussion: 11 -> 9 pages, 5 figures,
    5 tables. Draft banner under the title.
2026-07-06 Deep search results + paper v3 (better display and observations)
    - Deep 9-class run (0.05 mm grid, k<=15, up to 240 bounces): 13 verified
    designs incl. a NEW mid-Pareto point, 22.25 m in 172 mm
    (14 x CM254-100, preset drone_22m + spec sheet); margins improved.
    - Architecture boundaries stated as observations: ~25 m verified path
    ceiling (constellation crowding on the 1-inch aperture, not photon
    budget) and 141 mm minimum envelope.
    - Print-quality white-theme 3-D figures (fixed washed-out title and
    colorbar) plus two new display figures: envelope-vs-OPL Pareto map
    and T(R) coating curves (paper_figures.py).
    - Paper v3: 10 pages, 7 figures, 5 tables; README menu at R=0.999.
    Co-Aut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
    [verified_designs.csv]
2026-07-06 All data and imagery at R=0.999 (project mirrors) + longer-OPL pictures + paper v4
    - Presets, search constant, spec sheets, design JSONs, tolerance MCs and
    all figure titles now at the confirmed R = 0.999 (headline 86.7%,
    max-OPL 83.9%, throughput parametric note retained once).
    - New picture sets for the longer-path designs: drone_25m (176 passes,
    24.77 m) and drone_22m (182 passes, 22.25 m), dark + print-white,
    embedded in the README; drone_25m beam-path figure added to the paper.
    - Tolerance Monte-Carlos rerun at 0.999 for all four presets (drone_20m:
    T 86.3 +/- 1.7 %, drift 4.1 mrad, zero clipping).
    - Paper v4: 11 pages, 8 figures, 5 tables; clean 0.999 menu table and
    our-mir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
    [mc_summary.csv, mc_summary_drone_16cm.csv, mc_summary_drone_22m.csv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]
2026-07-06 Search v7: long-path hunt (k to 45, n to 720, hole-clearance sizing, M2 arg)
    At R = 0.999 a 30-50% throughput floor allows 700-1200 reflections, so
    the k cap (not photon budget) was the OPL ceiling. High-k patterns are
    many-lobed Lissajous that fill the mirror face quasi-2D; the exact
    worst-pair rule decides which fit. Stage A now also sizes the amplitude
    for HOLE clearance (hole radius + beam + margin against the nearest
    mirror-0 spot -- stricter than spot-spot separation and previously
    underestimated), and a --m2 flag sets the design-basis beam quality for
    all traced evaluations (hunts run at M2 = 1.1 for built-in realism).
    Analytic smoke: 90 candidates >= 30 m up to 70 m @ 47% T inside 18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
2026-07-06 Investigations report refreshed at R = 0.999
    ROC-compensation table now quotes throughput at the confirmed coating
    (86.5-87% for drone_20m across the full +/-1% band); trim rules,
    thermal windows and M2 verdicts are reflectivity-independent and
    unchanged.
    [study_m2.csv, study_roc_compensation.csv, study_thermal.csv]
2026-07-06 Relax mirror floor to N=6-16; add tolerance-aware menu selection
    - N range 6..16 (user relaxed the floor): N=7 packs to a ~97 mm
    envelope with near-diameter chords (s=3, AOI 12.9 deg), opening the
    sub-130 mm classes; N=6 has only grazing coprime skips and dies in
    the prescreen.
    - robust_menu.py: every feasible design gets a 100-trial research-grade
    Monte-Carlo; a design enters the published menu only if the p95
    spot-pattern walk fits inside its hole/sep margins and every trial
    completes the full path -- good tolerance becomes a selection
    criterion, not an afterthought.
2026-07-06 Physical per-trial robustness metrics in the tolerance engine
    Monte-Carlo trials now record what actually decides buildability:
    per-trial minimum spot separation and overlap flag (relative distances,
    which survive the coherent pattern walk), and the coupling-hole
    clearance of the launch mirror in each perturbed build. robust_menu
    uses them for two honest tiers: robust AS-BUILT (exit still leaves the
    1.3 mm hole with no realignment: walk p95 + beam < hole radius) and
    robust WITH the standard ring/launch trim (everything geometric holds;
    exit recentred during normal alignment). The previous criterion
    compared the coherent walk against relative margins and was over-
    conservative by construction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
2026-07-06 Tolerance-tiered menu, flight-tier winners, collimator section -- paper v5
    Robustness filter (physical per-trial criteria, research + flight
    grades) establishes the architecture map: 20.4 m robust at standard lab
    build; 29.0 m @ 76.6% (Ø183) and 20.7 m @ 81.6% (Ø141!) robust at
    flight-grade 0.1 mrad build (presets drone_29m, drone_14cm + specs +
    figure sets); 38.6 m ceiling requires active alignment (dense patterns
    lose spot identity at standard tolerances -- sep p05 0.04 mm).
    Paper v5: tolerance-tier column in the menu table, tier-boundary
    observations, and a new section 2.5 on injection-chain/collimator
    selection per supervisor guidance -- fibre-pigtailed DFB with a
    collimation-package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
    [robust_menu.csv, robust_menu_flight.csv, verified_designs.csv]
2026-07-06 Search v8: tolerance as a design input
    Two robustness-by-design controls: --walk-budget sizes every spot-pair
    and hole clearance for the expected relative spot walk of the target
    build grade (0.55 mm research-class instead of the 0.3-0.35 mm that
    made dense designs fail Monte-Carlo), flowing into the polish
    objective; --max-amp-gain rejects cells whose transverse error
    amplification 1/sin(theta) exceeds the bound (injected angular errors
    oscillate ~ 1/sin theta -- near-planar unit cells amplify build error
    2-3x). Goal: push the robust frontier itself, not the nominal one.
2026-07-06 Final robust tiers from merged hunts; 24.8 m promoted to flight tier
    Merged both hunts (30 unique feasible designs), re-filtered at research
    and flight grades with the physical criteria. Flight tier now: 29.0 m,
    24.8 m (promoted by the walk-budget re-polish: worst-case separation
    0.86 mm, 100% completion), 20.7 m @ Ø141, 20.4 m, 16.6 m, 14.9 m,
    13.6 m. Research tier: drone_20m (original launch variant; dedicated
    400-trial MC). Honest findings recorded: walk-budget margins harden
    designs (+30% worst-case separation on the headline); the 1/sin-theta
    amplification gate was empirically falsified; walk ~ sqrt(chords) puts
    the standard-tolerance ceiling near 145 chords -- and a drone needs the
    fl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
    [robust_menu.csv, robust_menu_flight.csv]
2026-07-06 Final paper draft: clean front matter, display equations, resolved refs
    - New title; banner, author block and data/code-availability section
    removed per user direction (authors to be added by the team).
    - Six numbered display equations in Section 2 (chord geometry, dual-
    plane phases, closure condition, constellation coordinates, eigenmode
    spot size, transmission law) with prose cross-references.
    - All six previously unverified references resolved against the
    literature (Graf 2017 OL 42:3137; Yang et al. Sensors 18:2680;
    Chang et al. OL 45:5897; CREMA arXiv:2112.00138; Dong et al.
    APL 108:011106; Liu et al. Sens. Act. B 220:1000).
    - Tier table and all numbers audited: 20.4 m stan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
2026-07-08 Prof-feedback round: wavelength-portable search, tri-gas verify, volume/overlap/entry metrics, construction-tolerance study
    [cell_metrics.csv]
2026-07-08 Entry/exit analysis: hole is a transverse-selective aperture worth k=9-19x OPL vs side slot; H2 2121.8 nm re-verification data
    [multigas_2121.8nm.csv]
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2026-07-08 Parametric housing CAD (STEP/STL for Fusion 360) + materials/construction-tolerance MC data
    [construction_tolerance.csv, materials_table.csv, tmpc_14cm.step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]
2026-07-08 IRsweep/literature comparison with overlap-factor and OD-noise analysis; tri-gas menu incl. new 23.8 m H2-robust design
    [robust_menu_h2.csv, robust_menu_h2_flight.csv, robust_menu_v9deep.csv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]
2026-07-08 New presets drone_24m_h2 (Optiland-validated at 2121.8 nm, 400-trial MC clean) and drone_27m; as-built specs; H2 row in cell metrics
    [cell_metrics.csv]
2026-07-08 Feedback-round figure set: overlap criterion, volume/PVR map, construction-tolerance bars, tri-gas matrix, H2/27m 3D renders, CAD renders; embedded in docs
2026-07-08 Half-inch search results tiered: 19.3 m/O93/37 mL active-tier star, 7.5 m/O122 flight-robust; W0/HOLE_R env for mini-collimator study; feature frontier v1
    [feature_frontier.csv, robust_menu_halfinch.csv, robust_menu_halfinch_flight.csv]
2026-07-08 Hardened-search tiers: new 25.7 m/O185 flight-robust, 15.3 m/O175 sparse budget candidate; mixed-SKU explorer rewritten with analytic unit-cell prescreen
    [robust_menu_hardened.csv, robust_menu_hardened_flight.csv]
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2026-07-08 Low-volume menu: 9.11 m/O129/90.8% flight-robust with 0.8 mm hole; 40 mL/190 m/L smallest robust; frontier updated (14 robust designs)
    [cell_metrics.csv, feature_frontier.csv, robust_menu_minihole.csv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]
2026-07-08 Tri-gas ceiling raised to 25.7 m (hardened design robust at all three gases); specs + CAD for 25.7/15.3/9.1 m designs
    [multigas_hardened_1512.2nm.csv, multigas_hardened_2121.8nm.csv, tmpc_9m_mini.step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]
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2026-07-08 400-trial flight MCs: 25.7 m and 15.3 m flawless (400/400), 9.1 m mini 99.0%
    [mc400_new_designs.csv]
2026-07-08 Assembly rules for new designs: 25.7 m trim 0.75 mm/% ROC, +-18 K Al; 9.1 m mini 0.52 mm/%, +-30 K Al; M2 1.3 both
    [study_m2_mini9m.csv, study_m2_trigas26m.csv, study_roc_mini9m.csv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]
2026-07-08 H2-native hardened tiering: tri-gas ceiling 25.72 m doubly confirmed (same design robust from both search directions)
    [robust_menu_h2hard_flight.csv]
2026-07-08 Operational physics audit: Jones-matrix polarization (s-launch eigenaxis rule, skip-3 diattenuation x6.4), vibration-to-signal budget, bounded remaining effects
    [polarization_audit.csv]
2026-07-08 Mixed-SKU verdict: verified 51.66 m/O180 mix-only design (alternating CM254-250/375) extends nominal ceiling 38.6->51.7 m; full study + closure map
    [mixed_sku_pass2.csv, mixed_sku_results.csv]
2026-07-08 Extended pass 2 (top-40): 51.7 m remains the singular feasible mixed point on 1-inch apertures
    [mixed_sku_pass2.csv]
2026-07-08 Max-OPL hunt verdict: 29.0 m confirmed as the passive-build ceiling (3rd independent walk-budget hunt); >29 m = active tier (38.6 uniform / 51.7 mixed)
    [robust_menu_maxopl.csv, robust_menu_maxopl_flight.csv]
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2026-07-08 Two-inch family verdict: 19.0 m/O182/86% (8 mirrors) + 11.6 m/O187/90% (7 mirrors) flight-robust; 19 m completes 100% at ALL process grades incl. FDM
    [construction_tolerance_2inch.csv, robust_menu_twoinch.csv, robust_menu_twoinch_flight.csv]
2026-07-08 Two-inch 19.0 m: tri-gas robust as-built + spec sheet; README two-inch section
    [multigas_twoinch_1512.2nm.csv, multigas_twoinch_2121.8nm.csv]
2026-07-08 Margin-aware mixed results: 30.5 m/O186 sep +0.33 and 20.8 m/O130 feasible; dedicated mixed MC harness (baseline dR + random flight errors)
    [mixed_sku_native.csv]
2026-07-08 Mixed 1-inch MC verdict: margin-aware winners are aperture-fragile (clip at 0.25 mm ROC / 0.1 mrad tilt) - active tier confirmed 3rd way; launching 2-inch mixed with both margins in objective
    [mixed_mc.csv, mixed_sku_native_winners.csv]
2026-07-08 Mixed-SKU endgame: constellation degeneracy isolated as the single blocker (1-inch aperture-fragility MC + 2-inch 14.7 mm headroom negative); study + paper Discussion updated (v2.2)
    [mixed_2inch.csv]
2026-07-08 Prof inputs round 2: three-tier tolerance framework docs archived + author list resolved
    Five Benoy documents (alignment-regimes, post-alignment-drift, full
    integrated comparison, IEEE-style paper, COMSOL mirror-only validation
    protocol) extracted to designs/prof_inputs/ with synthesis README
    mapping the C_build -> R_align -> D_op framework, destination drift
    envelopes, per-mount drone vectors and the 99.9 percent drone yield
    criterion onto our existing MC machinery. Author block: Rindani +
    Mishra (IITD-AD) fill the two open slots per the cc lines and the
    Ayachi-and-Naman reference in the review mail; Lennox -> Eblana
    Photonics; affiliation 2 -> Warwick (dept to confirm). Paper v2
    rebuilt (2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
2026-07-08 Capture-envelope study: prof acceptance model executed per design
    Per-DOF bisection of launch drift to the exit-clearance boundary for
    all 9 menu designs. P_cap 0.37-1.14 mm, Th_cap 3.0-18.8 mrad; every
    design passes the easy+Al-flexure and medium+hybrid-plastic demand
    vectors with 2.2-16x position and 5.5-94x angle margin. Angle capture
    is 1-2 orders above demand (re-entrance tolerates tilt; position drift
    translates the pattern ~1:1 toward the hole rim).
    [capture_envelope.csv]
2026-07-08 Hybrid plastic+Al-cartridge variant, COMSOL validation package, mc5000 harness
    - housing_cad: two_inch family + 19m_2in design + build_hybrid()
    (printable shell with integral base + Al mirror-cartridge annulus on
    three dowels + plastic lid with axial gas ports); STEP/STL for
    19m_2in hybrid+full-Al and 14cm hybrid.
    - hybrid_materials: CAD-volume mass table — hybrid saves 33-46 percent
    structure mass (14cm 817->435 g, 2-inch 1751->1056 g); 6 mm plastic
    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
    [comsol_geom_D130_9m_halfinch.csv, comsol_geom_D150_14cm_flight.csv, comsol_geom_D160_27m.csv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]
2026-07-08 Paper v2.3: three-tier tolerance chain executed end to end
    New section 2.8 (C_build capture check -> R_align + D_op, Eq. 10) and
    section 6.3 (capture envelopes Table 8 + Fig 13; 5000-trial composed
    drift MC Table 9: tri-gas 25.7 m, sparse 15.3 m and two-inch 19.0 m
    pass the 99.9 percent drone product criterion 5000/5000 on Al flexure;
    hybrid best carrier = two-inch at 95.0 percent). Section 6.4 reframed
    per the mitigate-by-alignment caution (zero-adjustment vs robust-after-
    trim vs drift separated) with the hybrid printed-shell/Al-cartridge
    architecture and CAD-volume mass table (33-46 percent saving). New
    section 6.7 commercial-solver validation package. Fixed pre-existing
    off-by-one table/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
    [mc5000_drone_yield.csv]
2026-07-08 Add hybrid + two-inch STL exports (print quoting) matching the STEP models
    [tmpc_14cm_hybrid_cartridge_al.stl, tmpc_14cm_hybrid_lid_plastic.stl, tmpc_14cm_hybrid_shell_plastic.stl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]
2026-07-09 Report v2.4: COMSOL content removed, author list trimmed to four, drone-yield figure added
    - Strip the commercial-solver (COMSOL) validation material entirely
    (abstract clause, section 6.7, conclusion next-step) so it can be
    reinstated once the licensed runs exist; renumber 6.8 -> 6.7.
    - Author list -> Sumant Varanasi, Thomas Benoy (co-first, corresponding),
    Rob Lennox (Eblana), Evgeny Rebrov (Warwick); affiliation 2 finalized
    to University of Warwick.
    - Add Fig. 14: 5000-trial drone-yield as trial-failure-rate (log) per
    mount architecture with the 99.9 percent product line; renumber the
    two downstream figure references.
    - 23 pp, 16 figures, 10 tables, 10 equations.
    Co-Authored-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
2026-07-15 COMSOL beam validation in-cell: flight design 20.2 m, width band agrees to 0.75% (pointwise drift = lattice dephasing, no bias)
    [comsol_beam.csv]
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2026-07-18 Static etalon OD noise floor per Benoy 2026-07-18 methodology: all 9 designs beat 1e-4 benchmark with tilted detector, flight design 1.6e-7 raw
    [etalon_od.csv]
